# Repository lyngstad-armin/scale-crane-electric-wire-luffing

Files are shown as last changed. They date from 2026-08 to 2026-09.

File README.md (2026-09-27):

# Bachelor Project:<br>Electric AHC Knuckle Boom

## Contents
- [User Manual](./User%20Manual/)
  - [Usage](./User%20Manual/usage.md)
  - [Rigging Guide](./User%20Manual/rigging-guide.md)
  - [Limitations](./User%20Manual/limitations.md)
- [CAD Files](./CAD/CAD_catalogue.md)
- [Assembly Guide & BOM](./Assembly%20Guide/ASSEMBLY.md)
- [Wiring Schematics](./Wiring%20Schematics/)

  - [System](./Wiring%20Schematics/SYSTEM_wiring.md)
  - [MRU & Server](./Wiring%20Schematics/MRU_wiring.md)
  - [Remote Control](./Wiring%20Schematics/RC_wiring.md)
  - [Crane Control Module](./Wiring%20Schematics/CCM_wiring.md)
  
  - [Stewart Platform](./Wiring%20Schematics/PLATFORM_wiring.md)
- [Firmware Documentation](./Firmware%20Documentation/)

  - [Crane Control Module](./Firmware%20Documentation/Crane%20Control%20Module/)     [[main.py]](/Firmware%20Documentation/Crane%20Control%20Module/main.py)
  - [Remote Control](./Firmware%20Documentation/Remote%20Control/)                   [[main.py]](/Firmware%20Documentation/Remote%20Control/main.py)

  - [Onboard Server](./Firmware%20Documentation/Onboard%20Server/)
  - [Motion Reference Unit](./Firmware%20Documentation/Motion%20Reference%20Unit/)

- Server / Digital Twin

According to agreement, the physical model of the crane & motion platform, in addition to necessary electronics and access to software, has been purchased by HVL (WNUoAS).

The associated IP, however, belongs to Palfinger Marine Norway AS, and shall be treated as such.
HVL retains no right to modify / manufacture / develop this concept further.
<br><br><br>
Designed, Built, Developed & Authored by 
<br><br>**Armin Lyngstad**, *reachable on ajlyngst@stud.ntnu.no*<br>
& <br>
**Jonas Hannisdal**,

# ***Please note that the documentation is a WIP and will be updated regularly to provide necessary information to safely operate and service the product***

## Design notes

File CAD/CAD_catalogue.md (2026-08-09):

# CAD Catalogue <br> File Explorer
[Back](../README.md)

## Contents
 - [Crane](#crane)
 - [Stewart Platform](#stewart-platform)
 - [Remote](#remote)

### **Crane**
|Part No. |Description |Amount |STL | CAD |
|-|-|-|-|-|
|**KBW-PD** | **Pedestal Assembly** |1|| N/A |
|KBW-PD-01 | Pedestal Bottom Plate | 1 | [File](./Modeling%20Format/Crane/Pedestal/KBW-PD-01.stl)| N/A |
|KBW-PD-02 | Pedestal Main Body | 1 | [File](./Modeling%20Format/Crane/Pedestal/KBW-PD-02.stl)| N/A |
|KBW-PD-03 | Slewing Motor Bracket | 1 | [File](./Modeling%20Format/Crane/Pedestal/KBW-PD-03.stl)| N/A |
|KBW-PD-04 | Gear Reduction Adapter | 2 | [File](./Modeling%20Format/Crane/Pedestal/KBW-PD-04.stl)| N/A |
|KBW-PD-05 | Slewing Gear | 2 | [File](./Modeling%20Format/Crane/Pedestal/KBW-PD-05.stl)| N/A |
---
|Part No. |Description |Amount |STL | CAD |
|-|-|-|-|-|
|**KBW-SB** | **Slewing Base Assembly** |1|| N/A |
| KBW-SB-01 | Slewing Base | 1 | [File](./Modeling%20Format/Crane/Slewing%20Base/KBW-SB-01.stl)| N/A |
| KBW-SB-02 | Outer Bearing | 2 | [File](./Modeling%20Format/Crane/Slewing%20Base/KBW-SB-02.stl)| N/A |
| KBW-SB-03 | Inner Bearing | 2 | [File](./Modeling%20Format/Crane/Slewing%20Base/KBW-SB-03.stl)| N/A |
| KBW-SB-04 | Bearing Pin | 140 | [File](./Modeling%20Format/Crane/Slewing%20Base/KBW-SB-04.stl)| N/A |
| KBW-SB-05 | Sheave Bracket | 1 | [File](./Modeling%20Format/Crane/Slewing%20Base/KBW-SB-05.stl)| N/A |
| KBW-SB-06 | Sheave Pin | 1 | [File](./Modeling%20Format/Crane/Slewing%20Base/KBW-SB-06.stl)| N/A |
---
|Part No. |Description |Amount |STL | CAD |
|-|-|-|-|-|
|**KBW-AF** | **A-Frame Assembly** |1|| N/A |
| KBW-AF-01 | A-Frame | 1 | [File](./Modeling%20Format/Crane/A-Frame/KBW-AF-01.stl)| N/A |
| KBW-AF-02 | Winch Plate | 3 | [File](./Modeling%20Format/Crane/A-Frame/KBW-AF-02.stl)| N/A |
| KBW-AF-03 | Winch Crown Gear | 3 | [File](./Modeling%20Format/Crane/A-Frame/KBW-AF-03.stl)| N/A |
| KBW-AF-04 | Winch Pinion Gear | 3 | [File](./Modeling%20Format/Crane/A-Frame/KBW-AF-04.stl)| N/A |
| KBW-AF-05 | Winch Axle | 3 | [File](./Modeling%20Format/Crane/A-Frame/KBW-AF-05.stl)| N/A |
| KBW-AF-06**A**| Winch Drum | 3 | [File](./Modeling%20Format/Crane/A-Frame/KBW-AF-06A.stl)| N/A |
| KBW-AF-06**B**| Mirrored Winch Drum | 3 | [File](./Modeling%20Format/Crane/A-Frame/KBW-AF-06B.stl)| N/A |
| KBW-AF-07 | Motor Encoder Bracket | 3 | [File](./Modeling%20Format/Crane/A-Frame/KBW-AF-07.stl)| N/A |
---
|Part No. |Description |Amount |STL | CAD |
|-|-|-|-|-|
|**KBW-BM** | **Boom Assembly** |1|| N/A |
|KBW-BM-01 | Boom | 1 | [File](./Modeling%20Format/Crane/Boom/KBW-BM-01.stl) | N/A
|KBW-BM-02 | Sheave Over Bracket | 2 |  [File](./Modeling%20Format/Crane/Boom/KBW-BM-02.stl) | N/A
|KBW-BM-03 | Sheave Under Bracket | 2 |  [File](./Modeling%20Format/Crane/Boom/KBW-BM-03.stl) | N/A
|KBW-BM-04 | Sheave Bracket Pins | 4 | [File](./Modeling%20Format/Crane/Boom/KBW-BM-04.stl) | N/A
|KBW-BM-05 | Boom Pin | 2 | [File](./Modeling%20Format/Crane/Boom/KBW-BM-05.stl) | N/A
|KBW-BM-06 | Jib Pin | 2 | [File](./Modeling%20Format/Crane/Boom/KBW-BM-06.stl) | N/A
|KBW-BM-07 | Boom Sheave | 4 | [File](./Modeling%20Format/Crane/Boom/KBW-BM-07.stl) | N/A
|KBW-BM-08 | Wire Termination Bracket | 1 | [File](./Modeling%20Format/Crane/Boom/KBW-BM-08.stl) | N/A
---
|Part No. | Description | Amount | STL | CAD |
|-|-|-|-|-|
|**KBW-JB**| **Jib Assembly** | 1 | |N/A|
|KBW-JB-01 | Jib | 1 | [File](./Modeling%20Format/Crane/Jib/KBW-JB-01.stl) | N/A
|KBW-JB-02 | Redirector Bracket | 1 |[File](./Modeling%20Format/Crane/Jib/KBW-JB-02.stl) | N/A
|KBW-JB-03 | Hoist Sheave | 1 | [File](./Modeling%20Format/Crane/Jib/KBW-JB-03.stl) | N/A
|KBW-JB-04 | Support Sheave | 2 | [File](./Modeling%20Format/Crane/Jib/KBW-JB-04.stl) | N/A
|KBW-JB-05 | Regular Sheave | 7 | [File](./Modeling%20Format/Crane/Jib/KBW-JB-05.stl) | N/A
|KBW-JB-06 | Short Shim | 4 | [File](./Modeling%20Format/Crane/Jib/KBW-JB-06.stl) | N/A
|KBW-JB-07 | Long Shim | 1 | [File](./Modeling%20Format/Crane/Jib/KBW-JB-07.stl) | N/A
|KBW-JB-09 | Redirector Pin | 1 | [File](./Modeling%20Format/Crane/Jib/KBW-JB-09.stl) | N/A
|KBW-JB-10 | Rope Exit Pin | 2 | [File](./Modeling%20Format/Crane/Jib/KBW-JB-10.stl) | N/A
|KBW-JB-11 | Rear Jib Pin | 2 | [File](./Modeling%20Format/Crane/Jib/KBW-JB-11.stl) | N/A
---
|Part No. | Description | Amount | STL | CAD |
|-|-|-|-|-|
|**KBW-CO**| **Compensator Assembly** |
|Yet to be added | 
---
### **Stewart Platform**
*Please note that the specified **amount** within each assembly is for **one** assembly,<br> whereas the specified **amount** for the assembly level **line 1** is for the entire project*
|Part No. |Description |Amount |STL | CAD |
|-|-|-|-|-|
|**SP-UV** | **Universal Joint Assembly** | **12** || N/A |
| SP-UV-01 | Knuckle | 2 | [File](./Modeling%20Format/Stewart%20Platform/Universal%20Joint/SP-UV-01.stl)| N/A |
| SP-UV-02 | Cross | 1 | [File](./Modeling%20Format/Stewart%20Platform/Universal%20Joint/SP-UV-02.stl)| N/A |
| SP-UV-03 | Cap | 4 | [File](./Modeling%20Format/Stewart%20Platform/Universal%20Joint/SP-UV-03.stl)| N/A |
---
|Part No. |Description |Amount |STL | CAD |
|-|-|-|-|-|
|**SP-GR** | **Gear Reduction Assembly** | **6** || N/A |
| SP-GR-01 | Housing | 1 | [File](./Modeling%20Format/Stewart%20Platform/Gear%20Reduction/SP-GR-01.stl)| N/A |
| SP-GR-02 | Stage 1 Lower | 1 | [File](./Modeling%20Format/Stewart%20Platform/Gear%20Reduction/SP-GR-02.stl)| N/A |
| SP-GR-03 | Stage 1 Sun Gear | 1 | [File](./Modeling%20Format/Stewart%20Platform/Gear%20Reduction/SP-GR-03.stl)| N/A |
| SP-GR-04 | Planet Gear | 6 | [File](./Modeling%20Format/Stewart%20Platform/Gear%20Reduction/SP-GR-04.stl)| N/A |
| SP-GR-05 | Stage 1 Upper | 1 | [File](./Modeling%20Format/Stewart%20Platform/Gear%20Reduction/SP-GR-05.stl)| N/A |
| SP-GR-06 | Stage 2 Lower | 1 | [File](./Modeling%20Format/Stewart%20Platform/Gear%20Reduction/SP-GR-06.stl)| N/A |
| SP-GR-07 | Stage 2 Upper | 1 | [File](./Modeling%20Format/Stewart%20Platform/Gear%20Reduction/SP-GR-07.stl)| N/A |
| SP-GR-08 | Stage 2 Sun Gear | 1 | [File](./Modeling%20Format/Stewart%20Platform/Gear%20Reduction/SP-GR-08.stl)| N/A |
---
|Part No. |Description |Amount |STL | CAD |
|-|-|-|-|-|
|**SP-TR** | **Transmission Assembly** | **6** || N/A |
| SP-TR-01 | Base Plate | 1 | [File](./Modeling%20Format/Stewart%20Platform/Transmission/SP-TR-01.stl)| N/A |
| SP-TR-02 | Top Plate | 1 | [File](./Modeling%20Format/Stewart%20Platform/Transmission/SP-TR-02.stl)| N/A |
| SP-TR-03 | Reduction Output Gear | 1 | [File](./Modeling%20Format/Stewart%20Platform/Transmission/SP-TR-03.stl)| N/A |
| SP-TR-04 | Actuator Input Gear | 1 | [File](./Modeling%20Format/Stewart%20Platform/Transmission/SP-TR-04.stl)| N/A |
| SP-TR-05 | Idler Gear | 1 | [File](./Modeling%20Format/Stewart%20Platform/Transmission/SP-TR-05.stl)| N/A |
---
|Part No. |Description |Amount |STL | CAD |
|-|-|-|-|-|
|**SP-AC** | **Actuator Assembly** | **6** || N/A |
| SP-AC-01 | Lower Connector Plate | 1 | [File](./Modeling%20Format/Stewart%20Platform/Actuator/SP-AC-01.stl)| N/A |
| SP-AC-02 | Lead Screw | 1 | [File](./Modeling%20Format/Stewart%20Platform/Actuator/SP-AC-02.stl)| N/A |
| SP-AC-04 | Housing | 1 | [File](./Modeling%20Format/Stewart%20Platform/Actuator/SP-AC-04.stl)| N/A |
| SP-AC-05 | Motion Tube | 1 | [File](./Modeling%20Format/Stewart%20Platform/Actuator/SP-AC-05.stl)| N/A |
| SP-AC-06 | Upper Connector Plate | 1 | [File](./Modeling%20Format/Stewart%20Platform/Actuator/SP-AC-06.stl)| N/A |
---
|Part No. |Description |Amount |STL | CAD |
|-|-|-|-|-|
|**SP-EE** | **End Effector Joint Assembly** | **6** || N/A |
| SP-EE-01 | Rotator | 1 | [File](./Modeling%20Format/Stewart%20Platform/End%20Effector%20Joint/SP-EE-01.stl)| N/A |
| SP-EE-02 | Housing | 1 | [File](./Modeling%20Format/Stewart%20Platform/End%20Effector%20Joint/SP-EE-02.stl)| N/A |
---
### **Remote**
|Part No. | Description | Amount | STL | CAD | 
|-|-|-|-|-|
| RMT-01 | Faceplate | 1 | [File](./Modeling%20Format/Remote/RMT-01.stl)| N/A |
| RMT-02 | Body | 1 | [File](./Modeling%20Format/Remote/RMT-02.stl)| N/A |
| RMT-03 | Backplate | 1 | [File](./Modeling%20Format/Remote/RMT-03.stl)| N/A |
| RMT-04 | Handle | 2 | [File](./Modeling%20Format/Remote/RMT-04.stl)| N/A |
| RMT-05 | Mirrored Handle | 2 | [File](./Modeling%20Format/Remote/RMT-05.stl)| N/A |
| RMT-06 | Handle Axle | 2 | [File](./Modeling%20Format/Remote/RMT-06.stl)| N/A |
| RMT-07 | Axle Collar | 2 | [File](./Modeling%20Format/Remote/RMT-07.stl) | N/A |

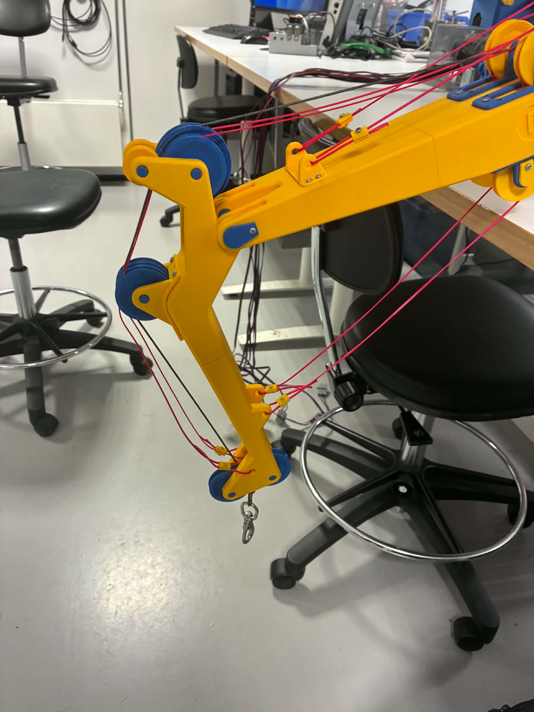
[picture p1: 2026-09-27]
.ignore/img/CRANE_TIP.jpg

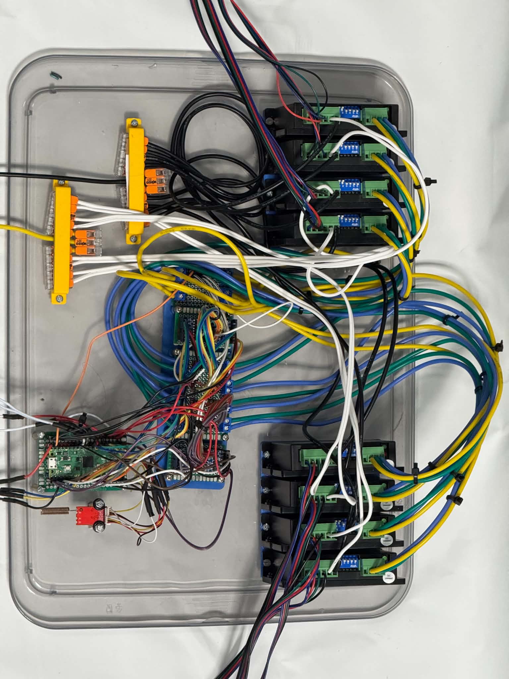
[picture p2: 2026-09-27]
.ignore/img/CCM_TOP2.jpg

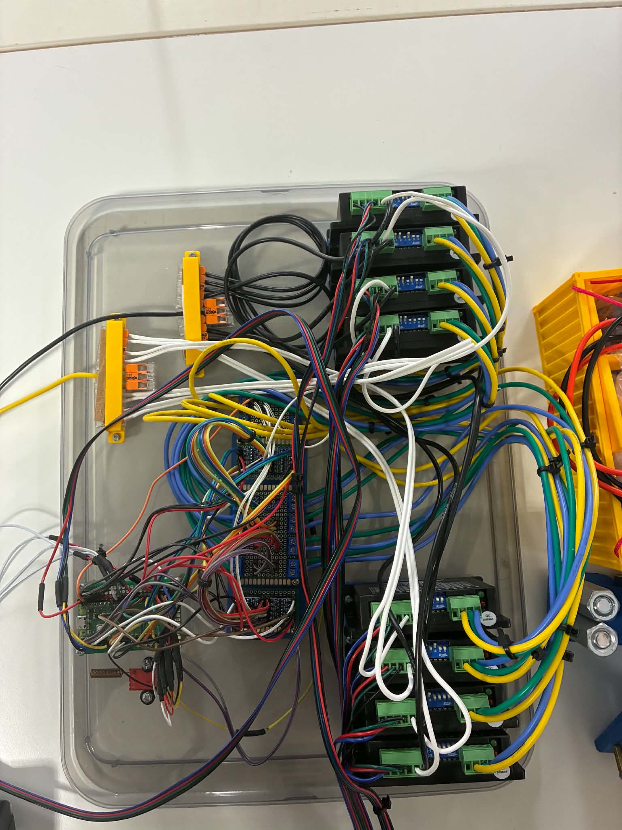
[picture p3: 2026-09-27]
.ignore/img/CCM_TOP.jpg

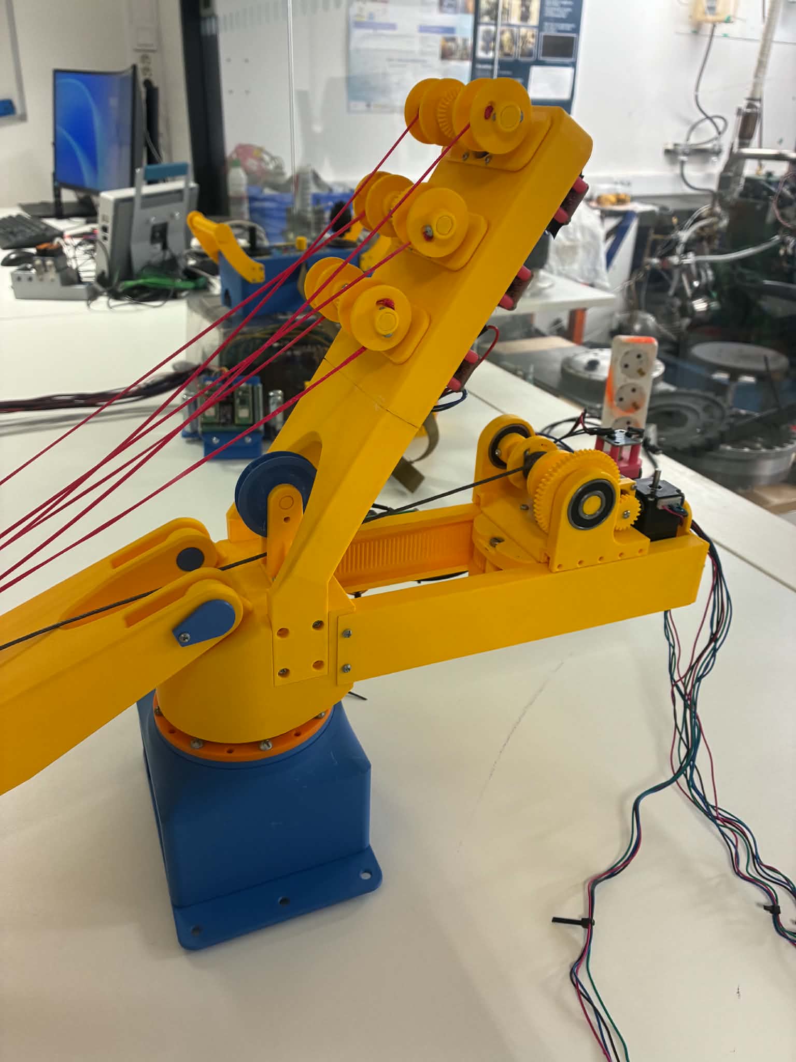
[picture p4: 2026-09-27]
.ignore/img/CRANE_REAR.jpg

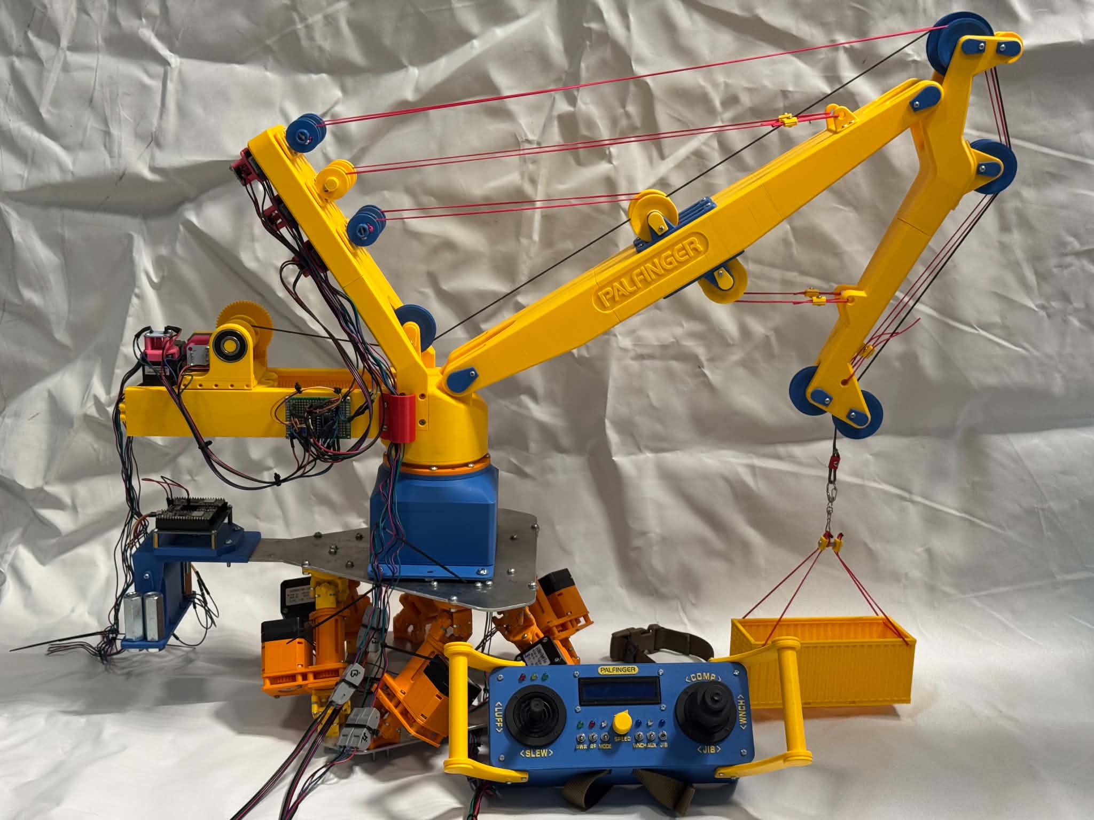
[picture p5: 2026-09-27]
.ignore/img/FULL_2.jpg

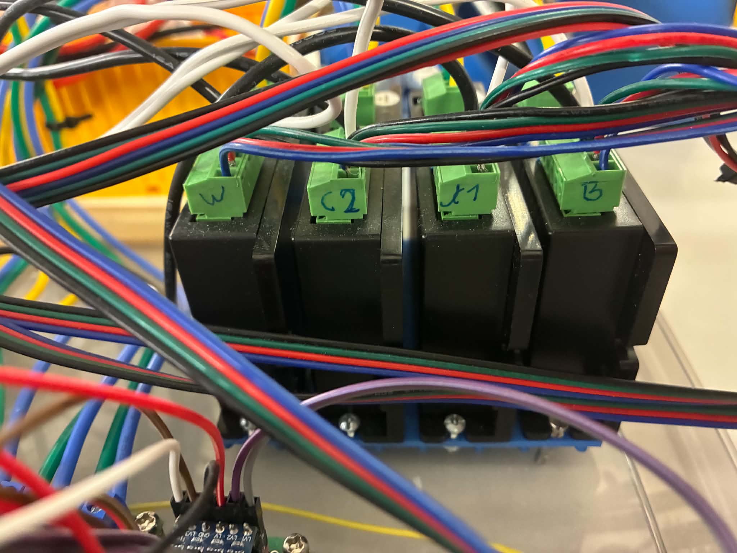
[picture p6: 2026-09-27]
.ignore/img/CCM_MARKING2.jpg

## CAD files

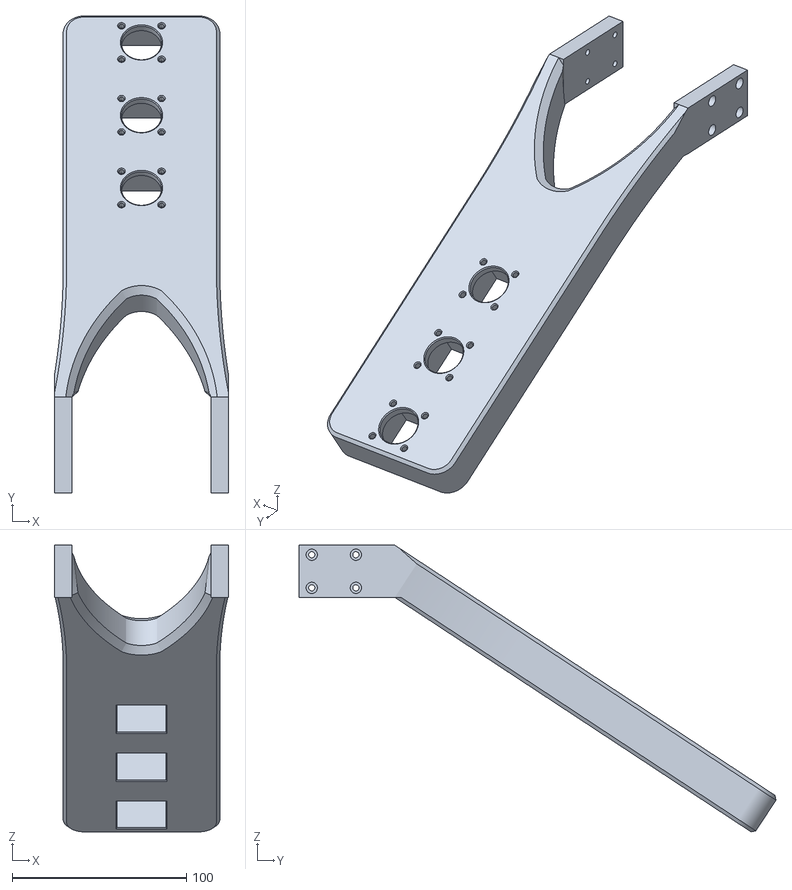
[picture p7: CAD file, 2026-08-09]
CAD/Modeling Format/Crane/A-Frame/KBW-AF-01.stl
100.0 x 273.9 x 164.6

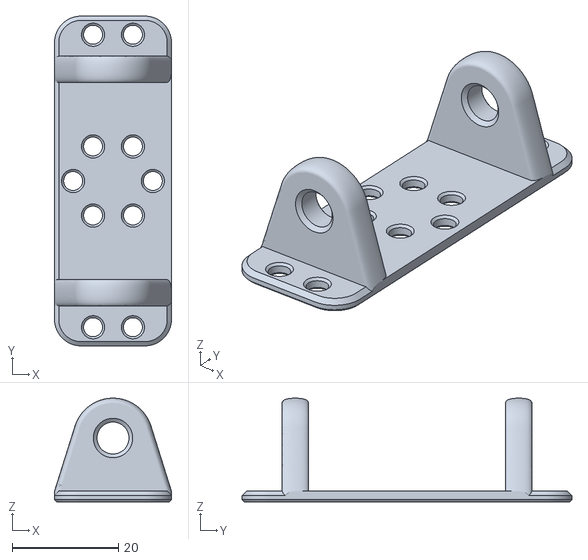
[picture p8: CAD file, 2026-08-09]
CAD/Modeling Format/Crane/Boom/KBW-BM-08.stl
22.0 x 62.0 x 19.5

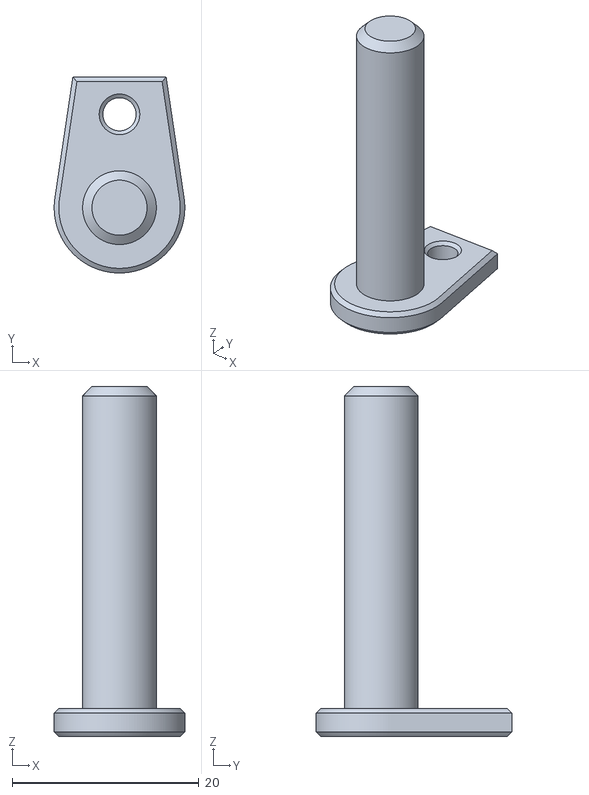
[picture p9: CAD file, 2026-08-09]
CAD/Modeling Format/Crane/Jib/KBW-JB-10.stl
14.0 x 21.0 x 37.5

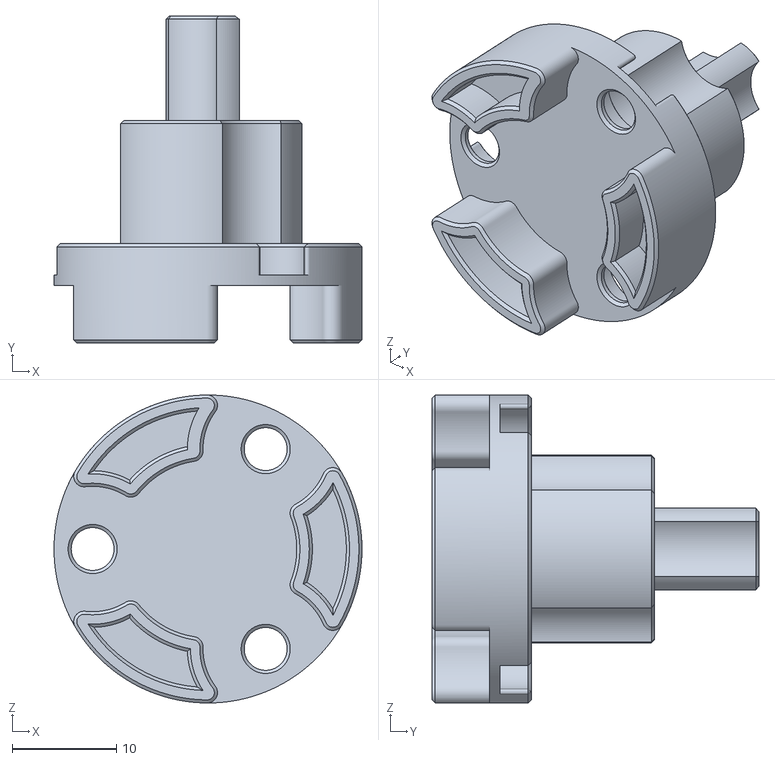
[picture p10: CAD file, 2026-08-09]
CAD/Modeling Format/Crane/Pedestal/KBW-PD-04.stl
29.5 x 31.3 x 29.5

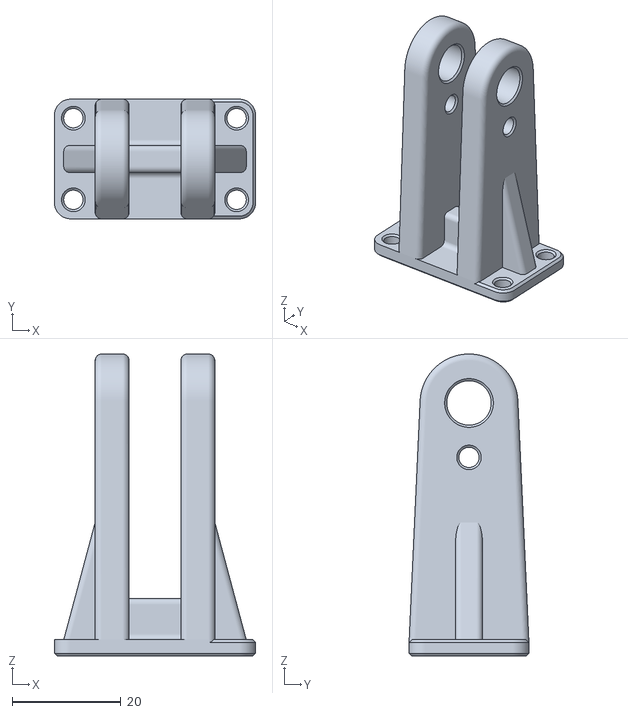
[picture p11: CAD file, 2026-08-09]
CAD/Modeling Format/Crane/Slewing Base/KBW-SB-05.stl
37.0 x 22.0 x 55.5

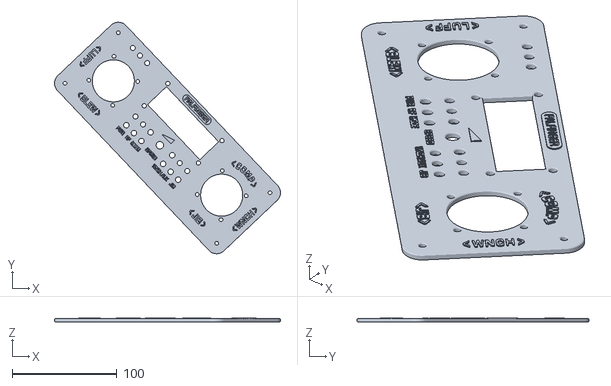
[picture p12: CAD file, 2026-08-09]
CAD/Modeling Format/Remote/RMT-01.stl
215.3 x 220.6 x 3.60

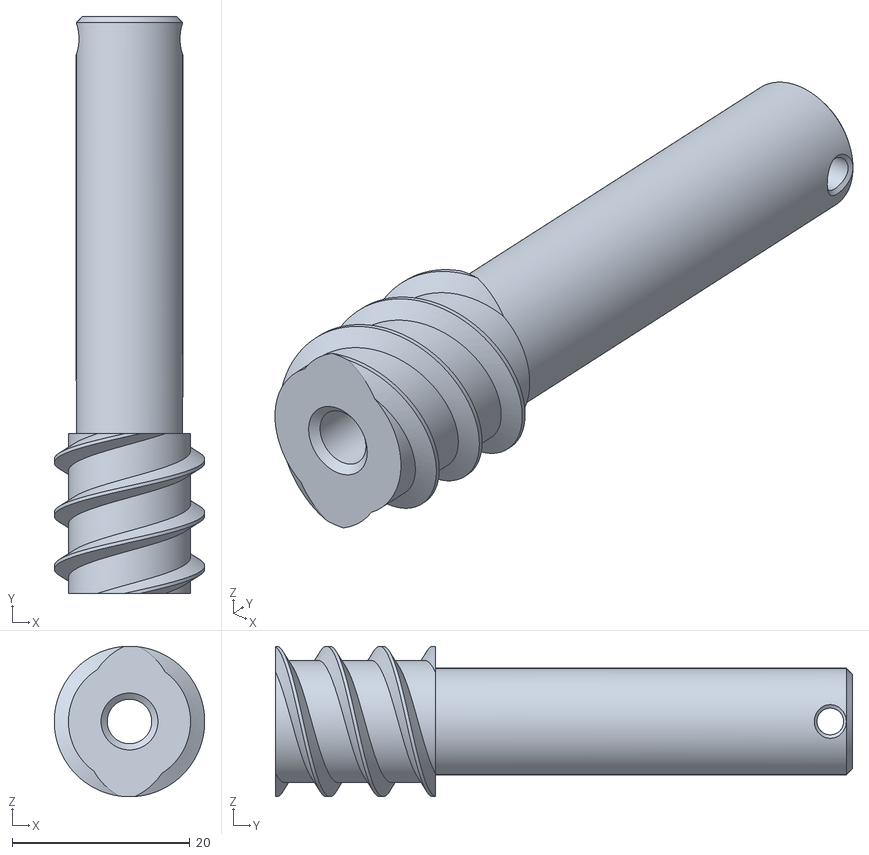
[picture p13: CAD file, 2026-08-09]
CAD/Modeling Format/Stewart Platform/Actuator/SP-AC-02.stl
16.9 x 65.0 x 16.9

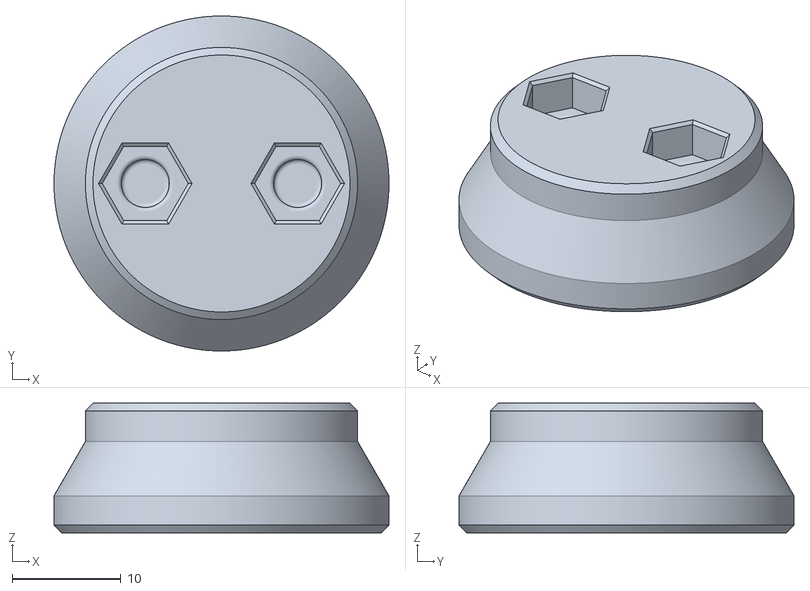
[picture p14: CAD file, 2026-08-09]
CAD/Modeling Format/Stewart Platform/End Effector Joint/SP-EE-01.stl
30.8 x 30.8 x 11.9

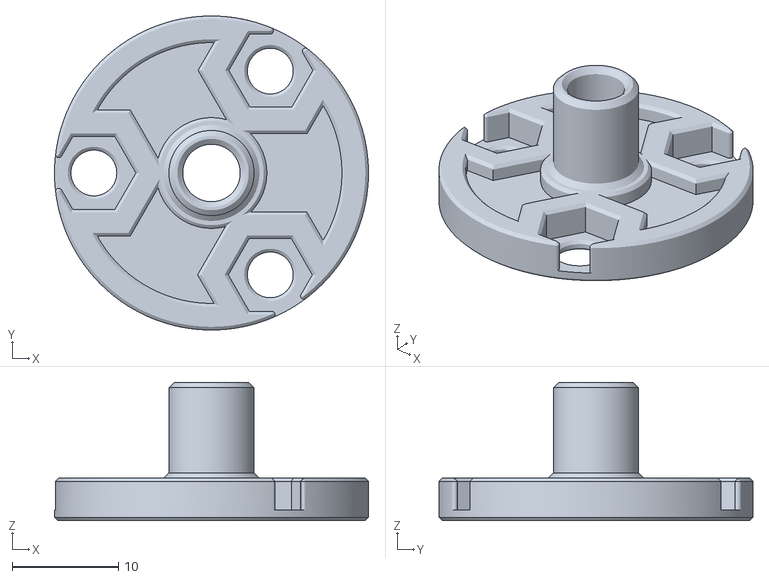
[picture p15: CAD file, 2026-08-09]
CAD/Modeling Format/Stewart Platform/Gear Reduction/SP-GR-05.stl
29.5 x 29.5 x 13.0

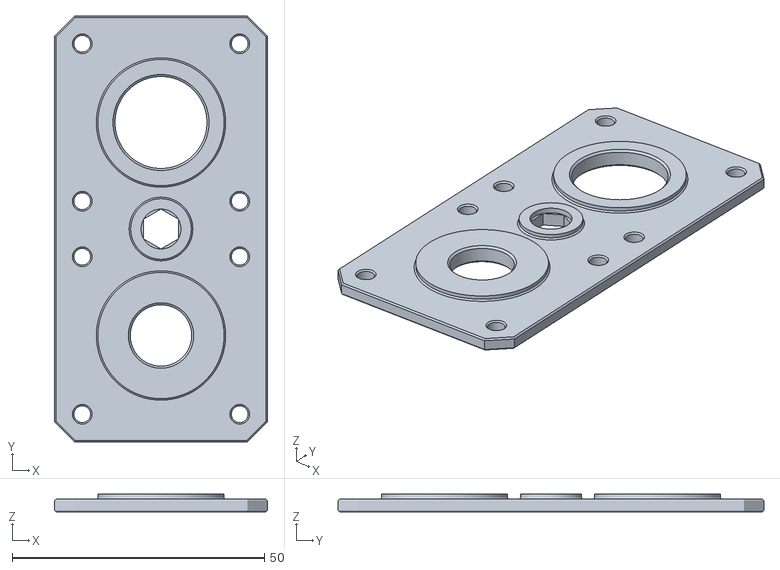
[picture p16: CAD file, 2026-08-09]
CAD/Modeling Format/Stewart Platform/Transmission/SP-TR-02.stl
42.2 x 84.4 x 3.50

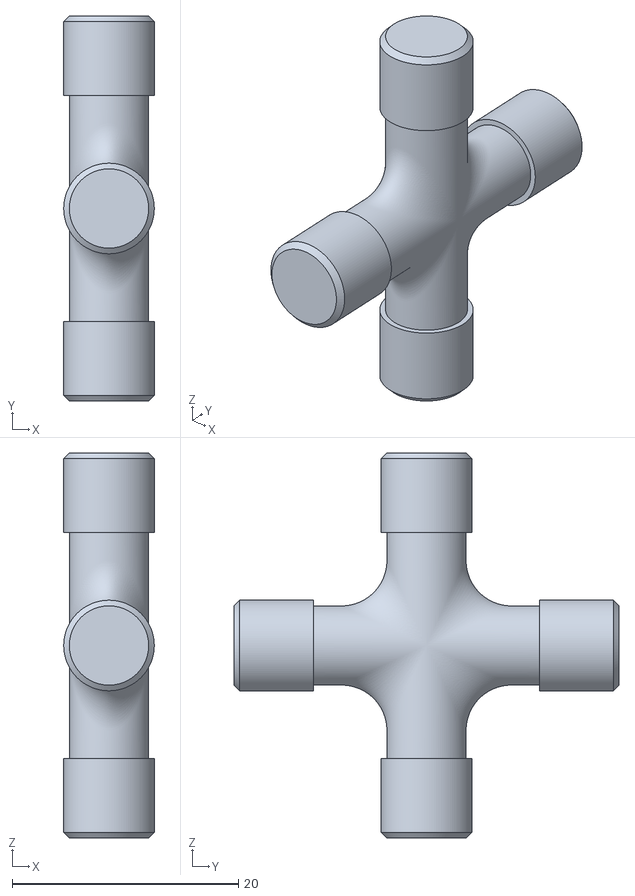
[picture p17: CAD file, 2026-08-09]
CAD/Modeling Format/Stewart Platform/Universal Joint/SP-UV-02.stl
8.00 x 34.0 x 34.0

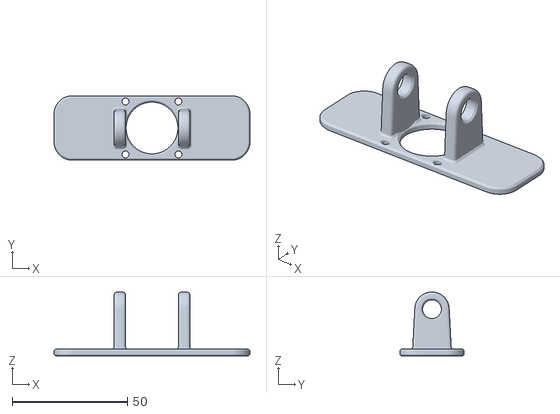
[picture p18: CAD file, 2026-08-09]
CAD/Modeling Format/Crane/A-Frame/KBW-AF-02.stl
85.2 x 28.0 x 27.8

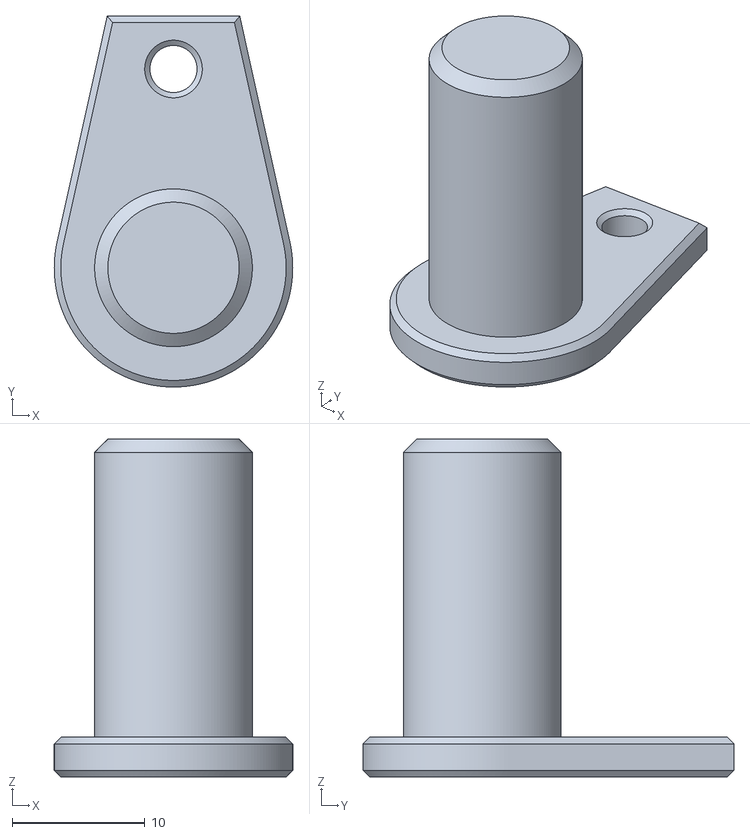
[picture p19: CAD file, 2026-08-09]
CAD/Modeling Format/Crane/Boom/KBW-BM-06.stl
18.0 x 28.0 x 25.5

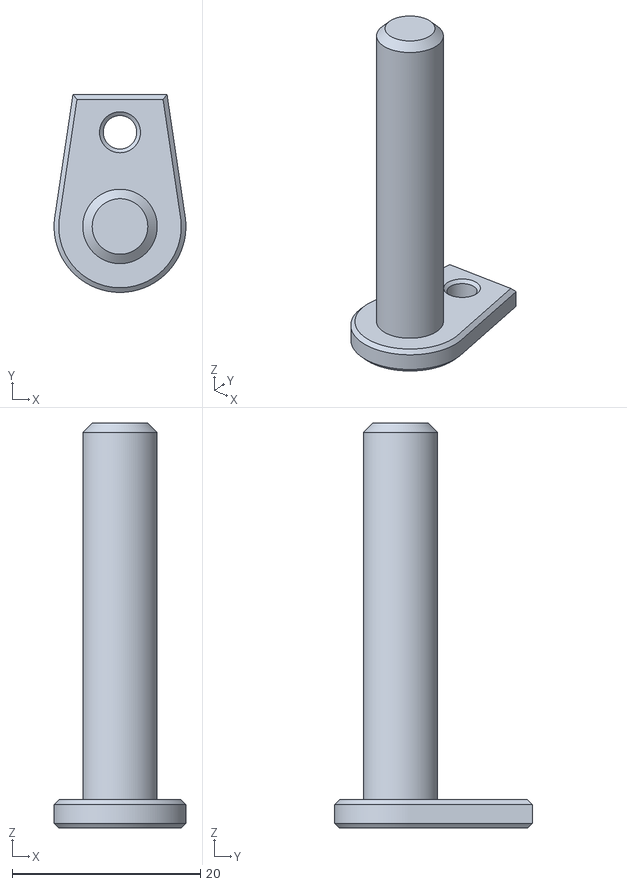
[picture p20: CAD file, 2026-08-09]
CAD/Modeling Format/Crane/Jib/KBW-JB-09.stl
14.0 x 21.0 x 43.0

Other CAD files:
CAD/Modeling Format/Crane/Pedestal/KBW-PD-03.stl
CAD/Modeling Format/Crane/Slewing Base/KBW-SB-02.stl
CAD/Modeling Format/Remote/RMT-05.stl
CAD/Modeling Format/Stewart Platform/Actuator/SP-AC-01.stl
CAD/Modeling Format/Crane/A-Frame/KBW-AF-03.stl
CAD/Modeling Format/Crane/A-Frame/KBW-AF-04.stl
CAD/Modeling Format/Crane/A-Frame/KBW-AF-05.stl
CAD/Modeling Format/Crane/A-Frame/KBW-AF-06A.stl
CAD/Modeling Format/Crane/A-Frame/KBW-AF-06B.stl
CAD/Modeling Format/Crane/A-Frame/KBW-AF-07.stl
CAD/Modeling Format/Crane/Boom/KBW-BM-02.stl
CAD/Modeling Format/Crane/Boom/KBW-BM-03.stl
CAD/Modeling Format/Crane/Boom/KBW-BM-04.stl
CAD/Modeling Format/Crane/Boom/KBW-BM-05.stl
CAD/Modeling Format/Crane/Boom/KBW-BM-07.stl
CAD/Modeling Format/Crane/Jib/KBW-JB-02.stl
CAD/Modeling Format/Crane/Jib/KBW-JB-03.stl
CAD/Modeling Format/Crane/Jib/KBW-JB-04.stl
CAD/Modeling Format/Crane/Jib/KBW-JB-05.stl
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

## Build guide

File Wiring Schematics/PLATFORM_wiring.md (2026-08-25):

# Stewart Platform <br>Wiring Schematics
[Back](../README.md)

## Commisioning/Decommisioning
```mermaid
%%{init: { 'flowchart': { 'nodeSpacing': 30, 'rankSpacing': 100, 'curve': 'linear' } } }%%
flowchart LR
classDef navy fill:#2e3c50,stroke:#5b9bd5,color:#fff
classDef crimson fill:#5c2525,stroke:#5b9bd5,color:#fff
classDef forest fill:#1f3d2b,stroke:#5b9bd5,color:#fff
classDef plum fill:#3b2e50,stroke:#5b9bd5,color:#fff
classDef teal fill:#1f3d3d,stroke:#5b9bd5,color:#fff
classDef amber fill:#5a3a1a,stroke:#5b9bd5,color:#fff
classDef magenta fill:#4a1f3d,stroke:#5b9bd5,color:#fff
classDef olive fill:#4a4a1f,stroke:#5b9bd5,color:#fff
classDef slate fill:#33383f,stroke:#5b9bd5,color:#fff
classDef indigo fill:#2a2a5c,stroke:#5b9bd5,color:#fff
classDef maroon fill:#4a1f2e,stroke:#5b9bd5,color:#fff
classDef umber fill:#3d2b1f,stroke:#5b9bd5,color:#fff
classDef steel fill:#1f3a4a,stroke:#5b9bd5,color:#fff
classDef mustard fill:#4a3f1f,stroke:#5b9bd5,color:#fff

RBPI[<br><br><br><br><br>Raspberry Pi Pico W<br><br><br><br><br><br>]
L1[Leg 1]
L2[Leg 2]
L3[Leg 3]
L4[Leg 4]
L5[Leg 5]
L6[Leg 6]

subgraph DR1[" "]
direction LR
D1
A1
end

subgraph DR2[" "]
direction LR
D2
A2
end

subgraph DR3[" "]
direction LR
D3
A3
end

subgraph DR4[" "]
direction LR
D4
A4
end

subgraph DR5[" "]
direction LR
D5
A5
end

subgraph DR6[" "]
direction LR
D6
A6
end

D1[Driver 1<br>BOB]
D2[Driver 2<br>BOB]
D3[Driver 3<br>BOB]
D4[Driver 4<br>BOB]
D5[Driver 5<br>BOB]
D6[Driver 6<br>BOB]
A1["A4988 1"]
A2["A4988 2"]
A3["A4988 3"]
A4["A4988 4"]
A5["A4988 5"]
A6["A4988 6"]

subgraph BRD[" "]
RBPI
W1[12V]
W2[GND]
USB
end

USB---|USB Micro-B|USB0["USB"]
W2---|WAGO|GND[PSU GND]
W1---|WAGO|12V[PSU 12V]

%%linkStyle 0,1,2,3,4,5 display:none

L1 ---|Connector<br>Marked 1| DR1 --- RBPI --- DR4 ---|Connector<br>Marked 4| L4
L2 ---|Connector<br>Marked 2| DR2 --- RBPI --- DR5 ---|Connector<br>Marked 5| L5
L3 ---|Connector<br>Marked 3| DR3 --- RBPI --- DR6 ---|Connector<br>Unmarked| L6

%%DR1 ---- RBPI
%%DR2 ---- RBPI
%%DR3 ---- RBPI
%%RBPI --- DR4
%%RBPI --- DR5
%%RBPI --- DR6

%%Style
RBPI:::forest
DR1:::crimson
DR2:::crimson
DR3:::crimson
DR4:::crimson
DR5:::crimson
DR6:::crimson
D1:::teal
A1:::indigo
D2:::teal
A2:::indigo
D3:::teal
A3:::indigo
D4:::teal
A4:::indigo
D5:::teal
A5:::indigo
D6:::teal
A6:::indigo
L1:::amber
L2:::amber
L3:::amber
L4:::amber
L5:::amber
L6:::amber
W1:::crimson
W2:::slate
USB:::indigo
USB0:::mustard
GND:::slate
12V:::crimson
```
<br>
<br>
<br>

## Platform GPIO Wiring
```mermaid
%%{init: { 'flowchart': { 'nodeSpacing': 30, 'rankSpacing': 100, 'curve': 'linear' } } }%%
flowchart LR
classDef navy fill:#2e3c50,stroke:#5b9bd5,color:#fff
classDef crimson fill:#5c2525,stroke:#5b9bd5,color:#fff
classDef forest fill:#1f3d2b,stroke:#5b9bd5,color:#fff
classDef plum fill:#3b2e50,stroke:#5b9bd5,color:#fff
classDef teal fill:#1f3d3d,stroke:#5b9bd5,color:#fff
classDef amber fill:#5a3a1a,stroke:#5b9bd5,color:#fff
classDef magenta fill:#4a1f3d,stroke:#5b9bd5,color:#fff
classDef olive fill:#4a4a1f,stroke:#5b9bd5,color:#fff
classDef slate fill:#33383f,stroke:#5b9bd5,color:#fff
classDef indigo fill:#2a2a5c,stroke:#5b9bd5,color:#fff
classDef maroon fill:#4a1f2e,stroke:#5b9bd5,color:#fff
classDef umber fill:#3d2b1f,stroke:#5b9bd5,color:#fff
classDef steel fill:#1f3a4a,stroke:#5b9bd5,color:#fff
classDef mustard fill:#4a3f1f,stroke:#5b9bd5,color:#fff

D1[Driver 1<br> BOB]
D2[Driver 2<br> BOB]
D3[Driver 3<br> BOB]
D4[Driver 4<br> BOB]
D5[Driver 5<br> BOB]
D6[Driver 6<br> BOB]

subgraph RBPI[Raspberry Pi Pico W]
    GPX1
    GPX2
    GPX3
    GPX4
    GPX5
    GPX6
    GPX7
    GPX8
    GPX9
    GPX10
    GPX11
    GPX12
end

GPX1 --- GPX7
GPX2 --- GPX8
GPX3 --- GPX9
GPX4 --- GPX10
GPX5 --- GPX11
GPX6 --- GPX12
linkStyle 0,1,2,3,4,5 display:none

D1 ---|PUL| GPX1
D1 ---|DIR| GPX2

D2 ---|PUL| GPX3
D2 ---|DIR| GPX4

D3 ---|PUL| GPX5
D3 ---|DIR| GPX6

GPX7 ---|PUL| D4
GPX8 ---|DIR| D4

GPX9 ---|PUL| D5
GPX10 ---|DIR| D5

GPX11 ---|PUL| D6
GPX12 ---|DIR| D6

%%Style
D1:::teal
D2:::teal
D3:::teal
D4:::teal
D5:::teal
D6:::teal
RBPI:::forest
GPX1:::plum
GPX2:::maroon
GPX3:::plum
GPX4:::maroon
GPX5:::plum
GPX6:::maroon
GPX7:::plum
GPX8:::maroon
GPX9:::plum
GPX10:::maroon
GPX11:::plum
GPX12:::maroon

%%Name
GPX1["GP0"]
GPX2["GP1"]
GPX3["GP8"]
GPX4["GP9"]
GPX5["GP6"]
GPX6["GP5"]
GPX7["GP28"]
GPX8["GP18"]
GPX9["GP26"]
GPX10["GP22"]
GPX11["GP21"]
GPX12["GP19"]
```
<br>
<br>
<br>

## Platform Power Wiring
```mermaid
%%{init: { 'flowchart': { 'nodeSpacing': 30, 'rankSpacing': 100, 'curve': 'linear' } } }%%
flowchart TB
classDef navy fill:#2e3c50,stroke:#5b9bd5,color:#fff
classDef crimson fill:#5c2525,stroke:#5b9bd5,color:#fff
classDef forest fill:#1f3d2b,stroke:#5b9bd5,color:#fff
classDef plum fill:#3b2e50,stroke:#5b9bd5,color:#fff
classDef teal fill:#1f3d3d,stroke:#5b9bd5,color:#fff
classDef amber fill:#5a3a1a,stroke:#5b9bd5,color:#fff
classDef magenta fill:#4a1f3d,stroke:#5b9bd5,color:#fff
classDef olive fill:#4a4a1f,stroke:#5b9bd5,color:#fff
classDef slate fill:#33383f,stroke:#5b9bd5,color:#fff
classDef indigo fill:#2a2a5c,stroke:#5b9bd5,color:#fff
classDef maroon fill:#4a1f2e,stroke:#5b9bd5,color:#fff
classDef umber fill:#3d2b1f,stroke:#5b9bd5,color:#fff
classDef steel fill:#1f3a4a,stroke:#5b9bd5,color:#fff
classDef mustard fill:#4a3f1f,stroke:#5b9bd5,color:#fff

D1[Driver 1<br> BOB]
D2[Driver 2<br> BOB]
D3[Driver 3<br> BOB]
D4[Driver 4<br> BOB]
D5[Driver 5<br> BOB]
D6[Driver 6<br> BOB]

subgraph PSU
    GND[Common GND]
    12V
end

subgraph DRV[" "]
    D1
    D2
    D3
    D4
    D5
    D6
end

subgraph RB["Raspberry Pi Pico W"]
    VBUS[VBUS<br>5V]
    USB
    3.3V
    GN[GND]
end

GND ---|To all BOB| D1 & D4
12V ---|To all BOB| D1 & D4
D3 & D6 ---|To all BOB| VBUS
GND --- GN

linkStyle 0,1,6 stroke:#2A2A2A,stroke-width:5px
linkStyle 2,3,4,5 stroke:#FF4D4D,stroke-width:4px
USB --- USB0["USB"]
linkStyle 7 stroke:#4a4,stroke-width:6px

D1 --- D2 --- D3
D4 --- D5 --- D6

%%style
12V:::crimson
VBUS:::crimson
GND:::slate
GN:::slate
RB:::forest
USB:::indigo
USB0:::mustard
3.3V:::crimson
PSU:::navy
DRV:::steel
D1:::teal
D2:::teal
D3:::teal
D4:::teal
D5:::teal
D6:::teal
```

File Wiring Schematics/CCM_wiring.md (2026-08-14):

# Crane Control Module<br>Wiring Diagrams
[Back](../README.md)
## External Communication / I2C Bus / Driver Wiring

```mermaid
%%{init: {'flowchart': {'curve': 'linear'}}}%%
flowchart LR
classDef style2 fill:#2e3c50,stroke:#5b9bd5,color:#fff
classDef style1 fill:#5c2525,stroke:#5b9bd5,color:#fff
classDef style3 fill:#242b2b,stroke:#5b9bd5,color:#fff
subgraph Driver Wiring
    direction TD

    DM1[Slew 1]:::style3
    DM2[Slew 2]:::style3
    DM3[Boom]:::style3
    DM4[Jib Under]:::style3
    DM5[Jib Over]:::style3
    DM6[Hoist]:::style3
    DM7[Comp 1]:::style3
    DM8[Comp 2]:::style3

    LLS1[Shifter 1]:::style1
    LLS2[Shifter 2]:::style1
    LLS3[Shifter 3]:::style1
    LLS4[Shifter 4]:::style1

    GPX1:::style2
    GPX2:::style2
    GPX3:::style2
    GPX4:::style2
    GPX5:::style2
    GPX6:::style2
    GPX7:::style2
    GPX8:::style2
    GPX01:::style2
    GPX02:::style2
    GPX03:::style2
    GPX04:::style2
    GPX05:::style2
    GPX06:::style2
    GPX07:::style2
    GPX08:::style2

%%linkStyle 0,1 display:none
GPX2 ---|PUL 3.3V| LLS1 ---|PUL 5V| DM1
GPX4 ---|PUL 3.3V| LLS1 ---|PUL 5V| DM2

GPX6 ---|PUL 3.3V| LLS2 ---|PUL 5V| DM3
GPX8 ---|PUL 3.3V| LLS2 ---|PUL 5V| DM4

GPX02 ---|PUL 3.3V| LLS3 ---|PUL 5V| DM5
GPX04 ---|PUL 3.3V| LLS3 ---|PUL 5V| DM6

GPX06 ---|PUL 3.3V| LLS4 ---|PUL 5V| DM7
GPX08 ---|PUL 3.3V| LLS4 ---|PUL 5V| DM8

GPX1 ---|DIR 3.3V| LLS1 ---|DIR 5V| DM1
GPX3 ---|DIR 3.3V| LLS1 ---|DIR 5V| DM2

GPX5 ---|DIR 3.3V| LLS2 ---|DIR 5V| DM3
GPX7 ---|DIR 3.3V| LLS2 ---|DIR 5V| DM4

GPX01 ---|DIR 3.3V| LLS3 ---|DIR 5V| DM5
GPX03 ---|DIR 3.3V| LLS3 ---|DIR 5V| DM6

GPX05 ---|DIR 3.3V| LLS4 ---|DIR 5V| DM7
GPX07 ---|DIR 3.3V| LLS4 ---|DIR 5V| DM8
end
```

```mermaid
flowchart LR
classDef style2 fill:#2e3c50,stroke:#5b9bd5,color:#fff
    classDef style1 fill:#5c2525,stroke:#5b9bd5,color:#fff
    classDef style3 fill:#242b2b,stroke:#5b9bd5,color:#fff
subgraph I2C Multiplexer Wiring
    GP1[GPX SDA]:::style2
    GP2[GPX SCL]:::style2

    MPXSD[SDA]:::style1
    MPXSC[SCL]:::style1
    SDA7:::style1
    SCL7:::style1
    SDA6:::style1
    SCL6:::style1
    SDA5:::style1
    SCL5:::style1
    SDA4:::style1
    SCL4:::style1
    SDA3:::style1
    SCL3:::style1

    ENC1[Jib Over]:::style3
    ENC2[Boom]:::style3
    ENC3[Jib Under]:::style3
    ENC4[Hoist]:::style3
    ENC5[Winch]:::style3

    X991[" "]
    style X991 display:none

GP1 --- MPXSD
GP2 --- MPXSC
SDA7 & SCL7 --- ENC1
SDA6 & SCL6 --- ENC2
SDA5 & SCL5 --- ENC3
SDA4 & SCL4 --- ENC4
SDA3 & SCL3 --- ENC5
MPXSD & MPXSC --- X991
SP1[CCM PICO]:::style2 --- SP2[MULTIPLEXER]:::style1 --- SP3[ENCODERS]:::style3
linkStyle 12,13,14,15 display:none

end
```

## Power Wiring CCM

```mermaid
%%{init: {'flowchart': {'curve': 'linear'}}}%%
flowchart TB

    classDef style2 fill:#2e3c50,stroke:#5b9bd5,color:#fff
    classDef style1 fill:#5c2525,stroke:#5b9bd5,color:#fff
    classDef style3 fill:#242b2b,stroke:#5b9bd5,color:#fff

subgraph Power Wiring
PSU:::style3
GND:::style3
12V:::style1
Driver:::style2
P5[Pico VBUS / 5V]:::style1
P3[Pico 3.3V]:::style1
LSH[Shifter]:::style2
PG[Pico GND]:::style3 

PSU ---> 12V --- Driver --- P5
GND --- LSH ---|LV| P3
linkStyle 3 display:none
GND --- Driver
PG ---|HV-side| LSH ---|HV| P5
LSH ---|LV-Side| PG

PSU ---> GND
end
```

## Absolute CCM Pico I/O Wiring

```mermaid
%%{init: {'flowchart': {'curve': 'linear'}}}%%
flowchart TB

    classDef style2 fill:#2e3c50,stroke:#5b9bd5,color:#fff
    classDef style1 fill:#5c2525,stroke:#5b9bd5,color:#fff
    classDef style3 fill:#242b2b,stroke:#5b9bd5,color:#fff

subgraph Absolute I/O

    subgraph CCM
    USB["USB"]:::style1
    GP0:::style1
    GP1:::style1
    GP2:::style1
    GP3:::style1
    GP4:::style1
    GP5:::style1
    GP6:::style1
    GP7:::style1
    GP8:::style1
    GP9:::style1
    GP10:::style1
    GP11:::style1
    GP12:::style1
    GP13:::style1
    GP14:::style1
    GP15:::style1
    GP16:::style1
    GP17:::style1
    GP18:::style1
    GP19:::style1
    GP20:::style1
    GP21:::style1
    GP22:::style1
    GP26:::style1
    GP27:::style1
    GP28:::style1
    end

    subgraph INPUT
    USBI[USB]:::style3

    TX[UART TX]:::style3
    RX[UART RX]:::style3
    MISO:::style3
    MOSI:::style3
    SCK:::style3
    CS:::style3
    SDA[SDA]:::style3
    SCL[SCL]:::style3
    end

    subgraph OUTPUT
    TXU[UART TX]:::style2
    RXU[UART TX]:::style2

    MOSIU[MOSI]:::style2
    MISOU[MISO]:::style2
    SCKU[SCK]:::style2
    CSU[CS]:::style2

    SDAU[SDA]:::style2
    SCLU[SCL]:::style2

    JO[Jib Over]:::style2
    JU[Jib Under]:::style2
    S1[Slew 1]:::style2
    S2[Slew 2]:::style2
    Hoist:::style2
    C1[Comp 1]:::style2
    C2[Comp 2]:::style2
    Boom:::style2
    end

    CCM[CCM PICO]:::style1
    INPUT[Input]:::style3
    OUTPUT[Output]:::style2

USBI --- USB
TX --- GP4 --- TXU
RX --- GP5 --- RXU
GP0 --- |PUL| JU
GP1 --- |DIR| JU
GP3 --- |PUL| JO
GP2 --- |DIR| JO
GP8 --- |PUL| C1
GP20 --- |DIR| C1
GP11 --- |PUL| C2
GP10 --- |DIR| C2
GP13 --- |PUL| Hoist
GP12 --- |DIR| Hoist
GP15 --- |PUL| Boom
GP14 --- |DIR| Boom
GP6 --- |PUL| S1
GP7 --- |DIR| S1
GP22 --- |PUL| S2
GP21 --- |DIR| S2
SDA --- GP26 --- SDAU
SCL --- GP27 --- SCLU
SCK --- GP18 --- SCKU
MISO --- GP16 --- MOSIU
MOSI --- GP19 --- MISOU
CS --- GP17 --- CSU
end
```

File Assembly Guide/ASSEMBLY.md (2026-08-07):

# Assembly <br>Guide
[Back](../README.md)

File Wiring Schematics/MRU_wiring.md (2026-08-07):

# MRU & Server <br>Wiring Schematics
[Back](../README.md)

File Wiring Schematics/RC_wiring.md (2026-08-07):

# Remote Control <br>Wiring Schematics
[Back](../README.md)

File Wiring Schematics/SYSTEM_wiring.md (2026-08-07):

# System Architechure &<br>Intermodular Wiring Schematic
[Back](../README.md)
## Intermodular Connections
```mermaid
%%{init: {'flowchart': {'curve': 'linear'}}}%%
flowchart TB
    classDef style2 fill:#2e3c50,stroke:#5b9bd5,color:#fff
    classDef style1 fill:#5c2525,stroke:#5b9bd5,color:#fff
    classDef style3 fill:#242b2b,stroke:#5b9bd5,color:#fff

subgraph Remote
end

subgraph Crane
 direction LR
    CCM
    MRU
    SERVER
end

subgraph Website
end

subgraph Platform
end

CCM <--->|UART| MRU <--->|UART| SERVER

Remote <--->|SPI| CCM
SERVER --->|Websocket| Website
Website --->|Websocket| Platform

%%style
Remote:::style3
Crane:::default
CCM:::style1
MRU:::style2
SERVER:::style2
Website:::style1
Platform:::style1
```
---
## System Power Wiring
```mermaid
%%{init: {'flowchart': {'curve': 'linear'}}}%%
flowchart TB
    classDef style2 fill:#2e3c50,stroke:#5b9bd5,color:#fff
    classDef style1 fill:#5c2525,stroke:#5b9bd5,color:#fff
    classDef style3 fill:#242b2b,stroke:#5b9bd5,color:#fff

subgraph PSU
    GND
    12V:::style1
    5V:::style1
end
PSU:::style3
CCM:::style3
MRU:::style3
SERVER:::style3

PLATFORM:::style2

GND & 12V & 5V --- CCM
5V --- PLATFORM
CCM --- MRU --- SERVER
```

## Wiring for commissioning/decom
```mermaid
%%{init: {'flowchart': {'curve': 'linear'}}}%%
flowchart TB
classDef navy fill:#2e3c50,stroke:#5b9bd5,color:#fff
classDef crimson fill:#5c2525,stroke:#5b9bd5,color:#fff
classDef forest fill:#1f3d2b,stroke:#5b9bd5,color:#fff
classDef plum fill:#3b2e50,stroke:#5b9bd5,color:#fff
classDef teal fill:#1f3d3d,stroke:#5b9bd5,color:#fff
classDef amber fill:#5a3a1a,stroke:#5b9bd5,color:#fff
classDef magenta fill:#4a1f3d,stroke:#5b9bd5,color:#fff
classDef olive fill:#4a4a1f,stroke:#5b9bd5,color:#fff
classDef slate fill:#33383f,stroke:#5b9bd5,color:#fff
classDef indigo fill:#2a2a5c,stroke:#5b9bd5,color:#fff
classDef maroon fill:#4a1f2e,stroke:#5b9bd5,color:#fff
classDef umber fill:#3d2b1f,stroke:#5b9bd5,color:#fff
classDef steel fill:#1f3a4a,stroke:#5b9bd5,color:#fff
classDef mustard fill:#4a3f1f,stroke:#5b9bd5,color:#fff

subgraph PSU
    GND
    12V:::style1
    5V:::style1
end

subgraph CCM
    V5[VBUS/VSUS<br> or USB]:::style1
    GN[GND<br>or USB]
    V12["12V (Drivers)"]:::style1
    GN12["GND (Drivers)"]
    TX[UART TX]
    RX[UART RX]
    V3[3.3V]:::style1
end

subgraph MRU[MRU & SERVER]
    TX1[UART TX]
    RX1[UART RX]
    GNM[GND]
    V31[3.3V]:::style1
end

subgraph I2C
    SDA
    SCL
end

subgraph DR["Driver<br>(for each)"]
    A+
    A-
    B+
    B-
end

subgraph MT["Motor<br>(for each)"]
    GRN
    BLK
    RED
    BLU
end

subgraph Actuation
    direction TB
    DR
    MT
end
GND ---|Jumper wire<br>DNC if USB connected| GN
GND ---|WAGO| GN12
5V ---|Jumper wire<br>DNC if USB connected| V5
CCM ---|Jumper wire| SDA & SCL
12V ---|WAGO| V12

A+ ---|WAGO| BLK
A- ---|WAGO| GRN
B+ ---|WAGO| RED
B- ---|WAGO| BLU

TX ---|Jumper wire| RX1
RX ---|Jumper wire| TX1
V3 ---|Jumper wire| V31
GN ---|Jumper wire| GNM

MRU --- Actuation
linkStyle 14 display:none

%%style
PSU:::default
5V:::crimson
12V:::crimson
V3:::crimson
V31:::crimson
RX:::mustard
TX1:::mustard
TX:::plum
RX1:::plum
V12:::crimson
V5:::crimson
RED:::maroon
B+:::maroon
A-:::forest
GRN:::forest
BLU:::navy
B-:::navy
SDA:::forest
SCL:::steel

```

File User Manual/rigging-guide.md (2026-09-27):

# Rigging Guide
[Back](../README.md)

## Setup
 1. Mount Crane to Stewart Platform using 6pcs M6 screws and nuts
 ---
 2. Connect Stewart Platform leg connectors to main board<br>

 *Graphical Representation in [Platform Wiring/Commisioning](/Wiring%20Schematics/PLATFORM_wiring.md)*
 
 ---
 3. Connect Motor Wiring from Crane to CCM<br>
 Match Colors and Names (W ,C1 ,C2 ,B ,J1 ,J2 ,S1 ,S2 )

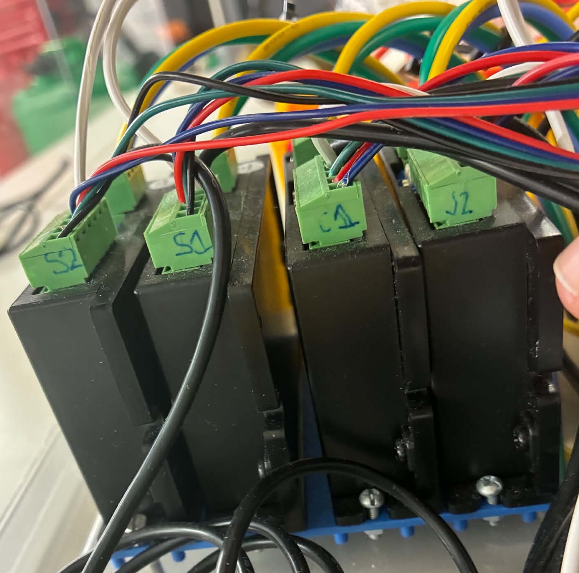
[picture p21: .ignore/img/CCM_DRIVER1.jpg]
CCM DRIVER NOTATION
 

 4. Connect I2C from Multiplexer (Rats nest on side of compensator)<br>
 Four wires; 2 jumper cables (white,grey), 2 one-sided jumpers with 16AWG ends (green)
 White,Grey are SDA/SCL lines for I2C, 16AWG wires are powersupply for multiplexer

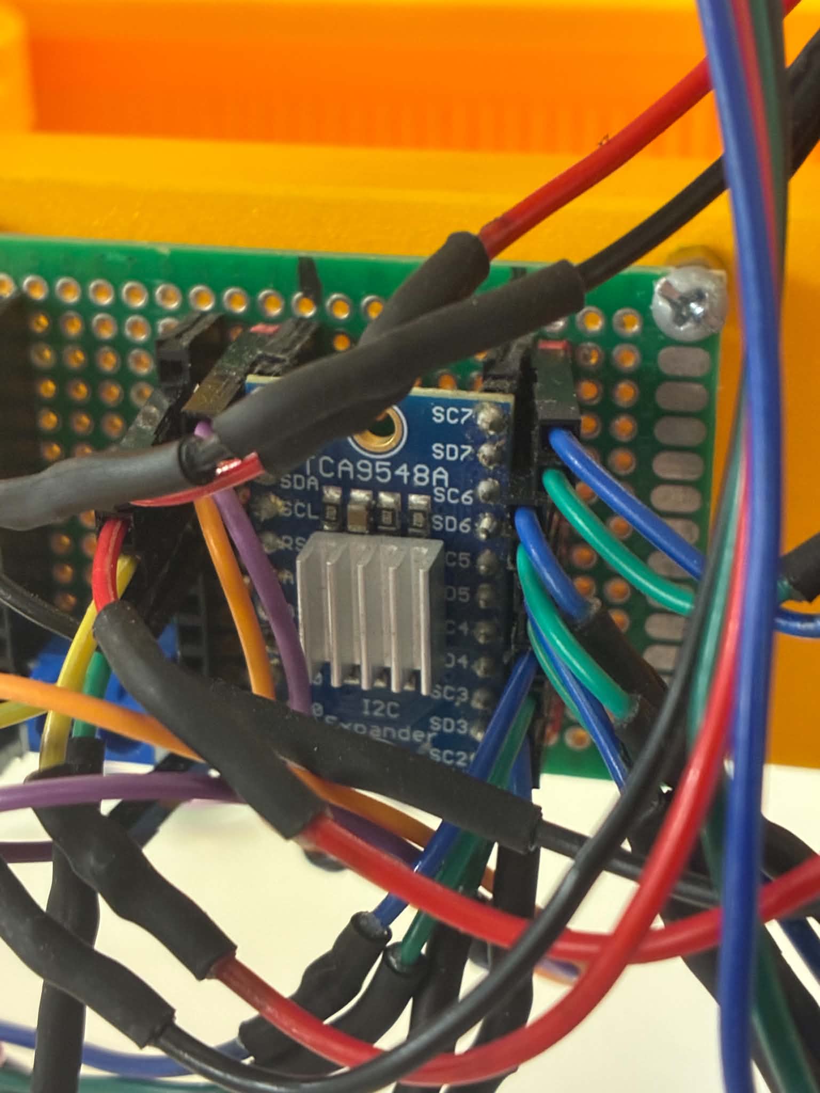
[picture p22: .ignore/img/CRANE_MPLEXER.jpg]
Multiplexer
 

 5. Connect UART Jumpers to CCM and MRU<br>
 Four wires; 4 jumper cables (blue,yellow,red,black)<br>

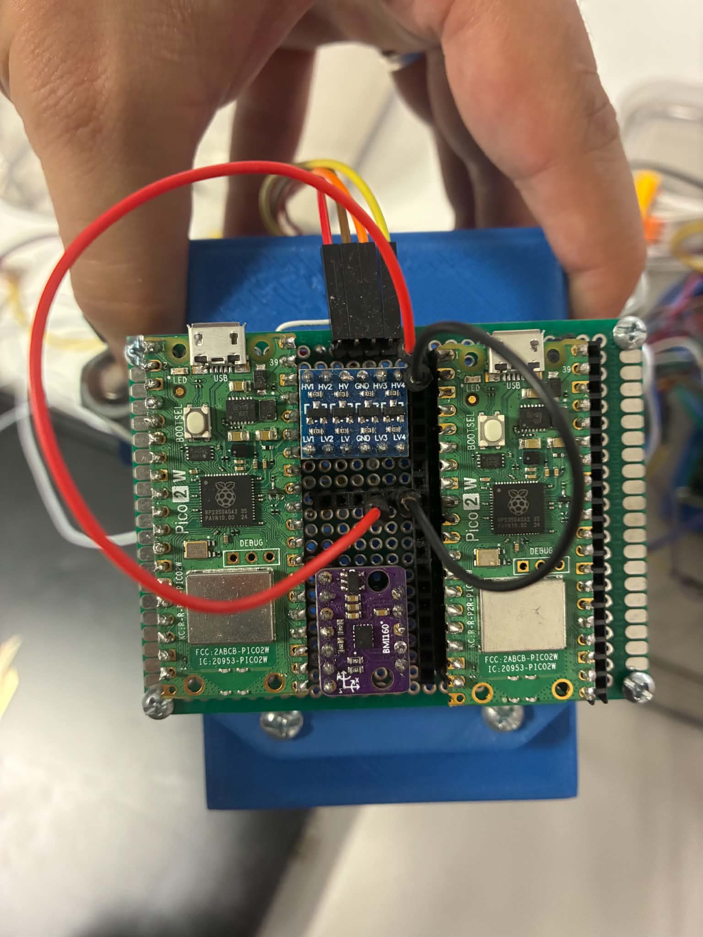
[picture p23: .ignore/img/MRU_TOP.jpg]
MRU


 *Graphical Representation in [System Wiring/Commisioning](/Wiring%20Schematics/SYSTEM_wiring.md)*
 
 ---

 6. Connect 12V Supply to both CCM and Platform Mainboard (Both boards should also be able to handle 24V, which will increase effective motor torque at speed)

 ---

 7. If controlling platform via Server, configure WiFi credentials through Thonny IDE while plugged into the Stewart Platform mainboard.
 This will also require configuring the WiFi credentials on the Server Module in the same way.

 ---

 8. Perform a simple connection check on the remote control

   - With the CCM unpowered, flick the power switch on the controller
   - Screen should read ```NLINK``` and signal indicators should blink red/green
   - Turn off remote
   - Then with the CCM **powered**, flick the power switch on the controller
   - Screen should read ```int dBm``` and signal indicators should be stable
   - If not, the remote is unable to communicate with the CCM <br>(Try flicking the antenna of the CCM and turning off and on again) <br> Should this not work, plug into the controller with Thonny IDE and read the debug REPL<br>Antenna ID should be ```0x14```
9. If the connection was successful, Crane should be ready to operate

## Wire Spooling

To ensure proper operation and response of the crane the luffing wires must spool correctly, at this scale it is especially difficult to keep the wire correctly spooled. Should the wire not have spooled correctly consider these options.
 <br>**Operating relevant winches with crane powered on**<br>
 **Unspooling/Respooling by hand with no power connected**

    - Unspool all wire on winch drum
    - With moderate tension (a respectable pinch) respool the drum
    - Push/Correct spooling as necessary underway

It is recommended to check all 7 Winches<br>
(Although the main winch does not care much for correct spooling)

*Reference Wire routing*

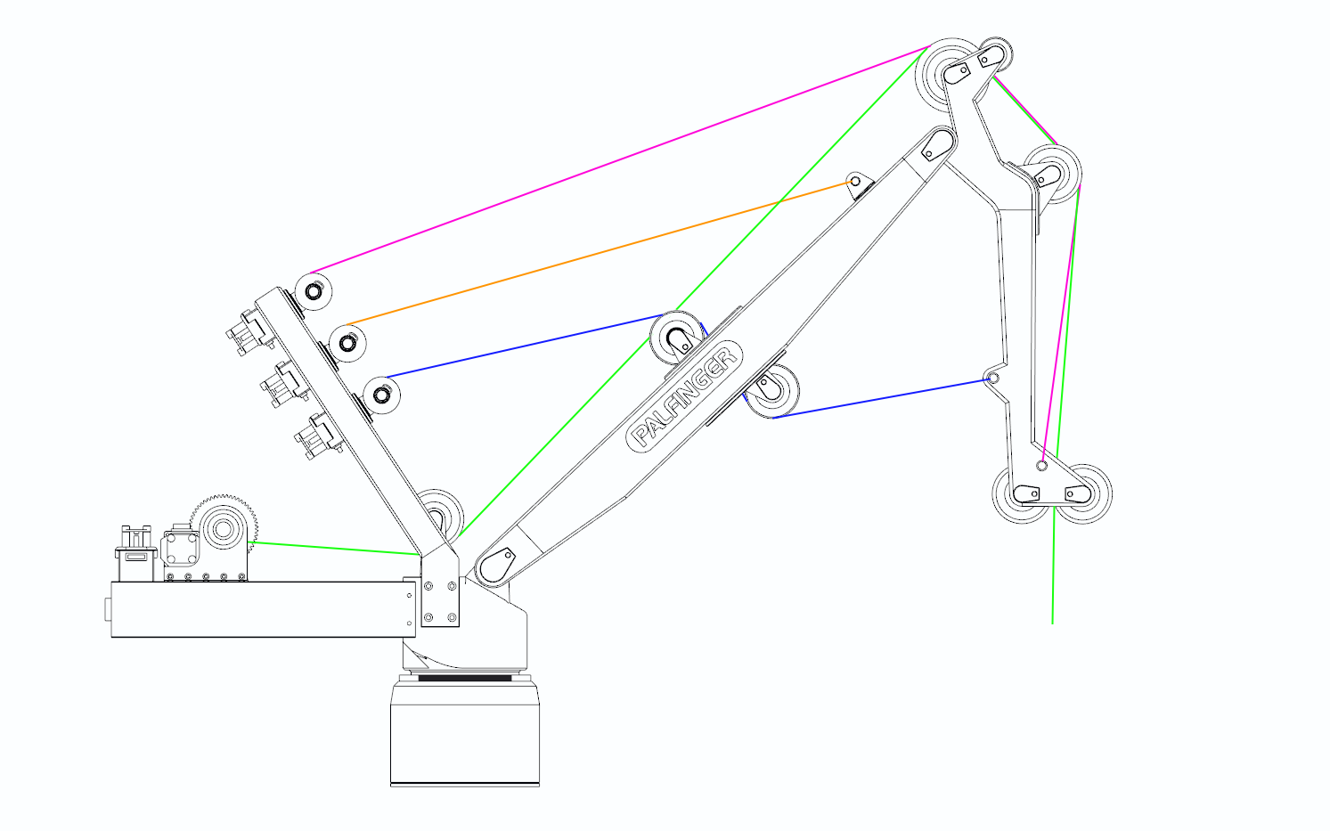
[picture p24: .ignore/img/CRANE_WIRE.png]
WIRE PATH


## Server Setup

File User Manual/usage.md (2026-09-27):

# How to Operate <br>

## Remote Control

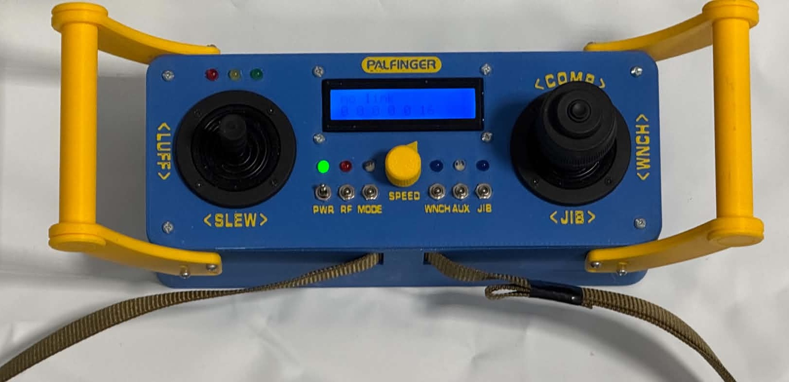
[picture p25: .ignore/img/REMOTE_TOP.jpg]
Remote


Joystick ``<SLEW>`` : Slews crane (Rotating the entire base)

Joystick ``<LUFF>`` : Operates boom (First link of crane up/down)

Joystick ``<JIB>`` : Operates jib (Second link of crane in/out)

Joystick ``<COMP>`` : Runs Compensator 'Cartridge' (Rear rail in/out)

Joystick ``<WNCH>`` : Main winch hoist (Load up/down)

Switch ``PWR`` : Power switch (Internal 9V battery)

Switch ``RF``: Encoder reset switch. Use ONLY when resetting encoders with crane in folded configuration.

Switch ``MODE``: Activate Heave Compensation.

Switch ``WNCH``: Debug Switch for reading error messages in Thonny IDE while connected to CCM

Switch ``AUX``: Unmapped

Switch ``JIB``: Switches operation mode of Jib Winches.

-``Off``: Synchronous (Both winches running)

-``On``: Only bottom wire

Knob ``Speed``:

-``button press`` : Enter menu

-``rotation`` : Adjust speed limit of each link

-``repeat button press``: Next entry in menu

## Encoder reset sequence

1. Ensure proper spooling on all winches, and run the crane to folded position.

2. Double check that all winches are tensioned at folded position.

3. Flick Switch ``RF`` On for 3 seconds, then off again.

4. Crane is now ready for operation, and Active Heave Compenstation

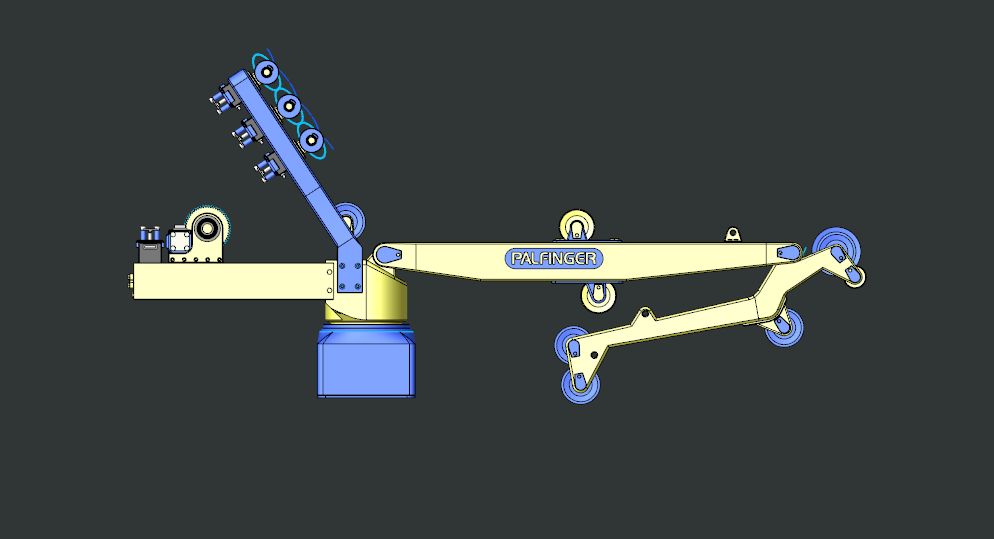
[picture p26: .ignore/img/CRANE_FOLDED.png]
Folded Position


[Back](../README.md)

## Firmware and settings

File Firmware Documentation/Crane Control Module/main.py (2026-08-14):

#MOTOR RC DECODING AND MOTOR COMMANDS
from velo import stacy, encoder, link
from machine import UART, Pin, SPI, WDT
import struct, time, gc, bisect, umatrix, math




'''===========================================================================================================
DECLARE ALL INPUTS AND OUTPUTS
RELATED TO MOTOR FUNCTION

FOR MOTOR:
OBJECTNAME = stacy(PUL,DIR)

FOR ENCODER:
OBJECTNAME = encoder(SDA,SCL,CHANNEL,SAVE ID, FREQUENCY[Hz], AVERAGE OVER X READS)

FOR LINK:
OBJECTNAME = link(MOTOR,ENCODER)
'''

#DECLARE MOTOR WIRING
jib2 = stacy(0,1)
jib1 = stacy(3,2)
comp1 = stacy(8,20)
comp2 = stacy(11,10)
winch = stacy(13,12)
boom = stacy(15,14)
slew1 = stacy(6,7,rid=1) #rid = 1 
slew2 = stacy(22,21)

#DECLARE ENCODERS
time.sleep(0.5)
Ejib2 = encoder(26,27,ch=5,sid=1,freq=60,mva=1)
Eboom = encoder(26,27,ch=6,sid=2,freq=60,mva=1)
Ejib1 = encoder(26,27,ch=7,sid=3,freq=60,mva=1)
Ecomp = encoder(26,27,ch=3,sid=5,freq=60,mva=1)
Ewinch = encoder(26,27,ch=4,sid=4,freq=60,mva=1)

#DECLARE MOTOR LINK
Ljib2 = link(jib2,Ejib2)

'''===========================================================================================================
LOAD ALL LOOKUP TABLES INTO MEMORY
 - BOOM ANGLE LOOKUP
 - RELATIVE BOOM SPEED LOOKUP
 - JIB ANGLE LOOKUP

'''

#LOAD BOOM LOOKUP TABLE
boom_pos : list = []
ang_deg  : list = []
with open('boom_angle.csv','r') as file:
    for line in file:
            row = line.rstrip('\n').rstrip('\r').split(',')
            boom_pos.append(int(row[0]))
            ang_deg.append(int(row[1]))
del file; del line; del row;
gc.collect()

#LOAD RELATIVE BOOM SPEED
jib1_speeds : list = []
jib2_speeds : list = []
ang_deg_boom : list = []
with open('boom_speed.csv','r') as file:
    for line in file:
        row = line.rstrip('\n').rstrip('\r').split(',')
        ang_deg_boom.append(int(row[0]))
        jib1_speeds.append(float(row[1]))
        jib2_speeds.append(float(row[2]))
del file; del line; del row;
gc.collect()

#JIB ANGLE LOOKUP TABLE
row = []
jib_set = []
with open('jib_angle.csv','r') as f:
    data = f.read()
for line in data.split('\r'):
    line = line.strip().strip('[]')
    if not line:
        continue
    row = [int(x) for x in line.split(',')]
    jib_set.append(row)
del f; del row; del line; del data;
#print(jib_set)

'''===========================================================================================================
USE LOOKUP TABLES TO CALCULATE
-BOOM ANGLE
-RELATIVE BOOM SPEED
-JIB ANGLE
'''

#BOOM ANGLE CALCULATION
def boom_angle(l,bp,ad):
    if bp == None:
        return 0
    if l >= 4875:
        return 70
    idex = bisect.bisect(bp,l)
    return ad[idex]

#BOOM SPEED CALCULATION
def boom_speed(act_angle,ang_deg_boom,jib1,jib2):
    if act_angle >= 70:
        return 0.97,0.79
    else:
        idex = bisect.bisect(ang_deg_boom,act_angle)
        return jib1[idex],jib2[idex]

#JIB ANGLE CALCULATION
def jib_angle(boom_angle,jib1e,file):
    jib1pos = []
    jib2pos = []
    offset = 2859
    if jib1e is None:
        return 0
    jibcheck = -jib1e #+ offset
    #print(file)
    for i in range(len(file)):
        #print(boom_angle,i)
        if i == boom_angle:
            sline = file[i]
    del i;
    try:
        l = enumerate(sline)
        for j, info in l:
            if j % 2 == 1:
                jib1pos.append(int(sline[j]))
            #elif j % 2 == 0:
            #    jib2pos.append(int(sline[j]))
        
        del l; del j; del info;
        idex = bisect.bisect(jib1pos,jibcheck)
        #print(idex)
        del jib1pos; del jib2pos;
    except Exception as e:
        print(f"{e}")
        idex = 0
    return 132 - idex*2

'''===========================================================================================================
CALCULATE
-WIRE POSITION
-COMPENSATOR POSITION
-SLEWING DEAD RECKONING
'''

#WIRE POSITION CALCULATION
def wlcalc(read):
    if read <= 0:
        read = -read
    read += 24840
    #print(read)
    i = 0
    length = 0
    gear_ratio = 2.7
    resolution = 400 * gear_ratio
    partial_spool = read % resolution
    spools = read // resolution
    layers = spools // 6
    spools_remainder = spools % 6
    #print(partial_spool, spools, layers, spools_remainder)
    for i in range(int(layers)):
        length += 6*(12+2*i)*math.pi
    length += spools_remainder*(12+(2*(i+1)))*math.pi
    length += (12+2*(i+1))*math.pi*partial_spool / resolution
    
    return round(length,1)

    #Setposition is 3 layers and 5 spools
    #Wire down is encoder negative direction
    #Small gear (driving) is 20 tooth
    #Big gear (driven) is 54 tooth
    #Gear ratio is 2.7

#COMPENSATOR POSITION
def comp_pos(getpos):
    pos = round((getpos) * 110/1160,1)
    if pos >= 110:
        Ecomp.setpos(1160)
        pos = 110.0
    elif pos <= 0:
        Ecomp.setpos(0)
        pos = 0.0
    return pos

    #front to back
    #0mm == fully forward
    #110mm == fully back

#SLEWING DEAD RECKONING
def slew_reck():
    steppos = slew1.getreck()
    angpos =steppos*360 / (38500)  % 360  //1
    return round(angpos,1)

'''===========================================================================================================
HEAVE COMPENSATION INITIALIZATION AND
HEAVE COMPENSATION CALCULATION
'''

#HEAVE COMPENSATION INITIALIZATION
sequence = [0,0,0]
count_over = 0
count_under = 0
def compensate(heave_save, hsave, sequence):
    global count_over, count_under
    #time.ticks_ms()
    hspeed  = -(heave_save+hsave) * 1160/110 *1
    limit = 5
    if abs(hspeed) <= limit:
        #count_under += 1
        hsave += heave_save
        hspeed = 0
        if abs(heave_save) <= 0.2:
            sequence = [sequence[1], sequence[2], None]
        else:
            sequence = [sequence[1], sequence[2], 'On']
        if sequence == [None, None, None]:
            COMP_OFF()
        #print(sequence)
        return hspeed, heave_save, hsave, sequence
    #count_over += 1
    if save_comp < 108 and hspeed >= limit:
        COMP_ON(1)
        COMP_SPD(hspeed,1)
        pass
    elif save_comp > 2 and hspeed <= -limit:
        COMP_ON(0)
        COMP_SPD(-hspeed,0)
        pass
    hsave = 0
    return hspeed, heave_save, hsave, sequence

#===== HEAVE CALCULATION ======
def heave_calc(POS, th1,th2,th3,th4,rolld,hd):
    th4 = -th4
    degrad = math.pi / 180
    
    #POS      TUPLE POSITION VECTORS
    #TH1            ROLL ANGLE (RAD)
    #TH2            SLEW ANGLE (RAD)
    #TH3            BOOM ANGLE (RAD)
    #TH4            JIB  ANGLE (RAD)
    #ROLLD    ANGULAR VELOCITY (RAD/S)
    #HD       LINEAR  VELOCITY (mm/S)
    
    #OUTPUT XCDOT3  LINEAR VELOCITY 3-AXIS REP (mm/S)
    
    #Position Vectors (constant)
    P_PS, P_SB, P_BJ, P_JR = POS
    cos = math.cos
    sin = math.sin
    #Relative Rotation Matrices
    
    c1, s1 = cos(th1), sin(th1)
    c2, s2 = cos(th2*degrad), sin(th2*degrad)
    c3, s3 = cos(th3*degrad), sin(th3*degrad)
    c4, s4 = cos(th4*degrad), sin(th4*degrad)
    
    R1 = umatrix.matrix([1,0,0],[0,c1,-s1],[0,s1,c1])  #ROLL
    R21 = umatrix.matrix([c2,-s2,0],[s2,c2,0],[0,0,1]) #SLEW
    R32 = umatrix.matrix([1,0,0],[0,c3,-s3],[0,s3,c3]) #BOOM
    R43 = umatrix.matrix([1,0,0],[0,c4,-s4],[0,s4,c4]) #JIB
    #Additional Relative Rotations
    R21T = R21.transpose
    R31T = R21T * R32.transpose
    R41T = R31T * R43.transpose 
    #Absolute Rotation Matrices
    R2 = R1 * R21
    R3 = R2 * R32
    R4 = R3 * R43
    #Angluar Velocities
    W1 = umatrix.matrix([rolld],[0],[0])
    #Linear Velocity (Heave)
    #ht = umatrix.matrix([0,0,hd]).transpose
    #Lie Group
    #e3 = umatrix.matrix([0,0,1])
    #Simplify multiplication order
    R1C = P_PS*W1
    R2C_1 = R21T*W1
    R2C_2 = P_SB*R2C_1
    R3C_1 = R31T*W1
    R3C_2 = P_BJ*R3C_1
    R4C_1 = R41T*W1
    R4C_2 = P_JR*R4C_1
    
    XCDOT3 = ( R1 * R1C + R2 * R2C_2 + R3 * R3C_2 + R4 * R4C_2)
    return float(hd + XCDOT3[2][0])

'''===========================================================================================================
RADIO SETUP AND CREATE HELPER FUNCTIONS FOR SPI ANTENNA
'''

#SPI
spi = SPI(0, baudrate=2_000_000, polarity=0, phase=0,
          firstbit=SPI.MSB, sck=Pin(18), mosi=Pin(19), miso=Pin(16))
cs  = Pin(17, Pin.OUT, value=1)
#UART
uart1 = UART(1, baudrate=115200, tx=4, rx=5)

#CC1101 HELPERS
def strobe(cmd):
    cs(0); spi.write(bytes([cmd])); cs(1)

def read_status(addr):
    cs(0); spi.write(bytes([addr | 0xC0]))
    buf = bytearray(1); spi.readinto(buf); cs(1)
    return buf[0]

def write_reg(addr, val):
    cs(0); spi.write(bytes([addr, val])); cs(1)

def read_fifo(n):
    cs(0); spi.write(bytes([0xFF]))
    buf = bytearray(n); spi.readinto(buf); cs(1)
    return buf

def rssi_dbm(raw):
    return (raw - 256) / 2 - 74 if raw >= 128 else raw / 2 - 74

def flush_and_rx():
    strobe(0x36); strobe(0x3A); time.sleep_us(100); strobe(0x34)

def send_packet(data):
    strobe(0x36); strobe(0x3B); time.sleep_us(100)
    cs(0); spi.write(bytes([0x7F])); spi.write(bytes([len(data)])); spi.write(data); cs(1)
    strobe(0x35)
    deadline = time.ticks_add(time.ticks_ms(), 50)
    while read_status(0xF5) not in (0x01, 0x0D):
        if time.ticks_diff(deadline, time.ticks_ms()) <= 0:
            break
        time.sleep_us(50)

def wait_packet(timeout_ms):
    deadline = time.ticks_add(time.ticks_ms(), timeout_ms)
    prev = 0; stable = 0
    while True:
        rxb = read_status(0xFB) & 0x7F
        if rxb > 0 and rxb == prev:
            stable += 1
            if stable >= 3:
                return rxb
        else:
            stable = 0
        prev = rxb
        if time.ticks_diff(deadline, time.ticks_ms()) <= 0:
            return 0
        time.sleep_us(100)

partnum = read_status(0xF0)
version = read_status(0xF1)
print(hex(partnum))
print(hex(version))

'''===========================================================================================================
DECLARE DECODING LISTS AND
DECLARE SKEWED POSITIONAL VECTORS FOR HEAVE COMPENSATION
'''

#DECLARE PAYLOAD LISTS FOR DECODING
zero     : list = [0]
zerobool : list = [False]
DEC_AX   : list = zero*5
DEC_SPD  : list = zero*5
DEC_DIR  : list = zero*5
DEC_SW   : list = zero*7
DATA     : list = zero*6


#DECLARE POSITION VECTORS FOR HEAVE
P_PS = umatrix.matrix( [     0,	 103.6,	  0.0],
                           [-103.6,	     0,	   0.0],
                           [   0.0,	  0.0,	     0] )
#(0,0,103.6)
    
P_SB = umatrix.matrix( [     0,	 -76.67,	22.58],
                           [76.67,	     0,	   0.0],
                           [-22.58,	  0.0,	     0] )
#(0,22.6,76.7)
P_BJ = umatrix.matrix( [     0,	   0.0,	500.0],
                           [  0.0,	     0,	   0.0],
                           [ -500.0,	  0.0,	     0] )
#(0,500,0)    
P_JR = umatrix.matrix( [      0,	110.2,	286.4],
                        [ -110.2,	      0,	    0.0],
                        [ -286.4,	   0.0,	      0] )

#(0,286.4,-110.2)
POS = P_PS.transpose, P_SB.transpose, P_BJ.transpose, P_JR.transpose
del P_PS; del P_SB; del P_BJ; del P_JR


'''===========================================================================================================
DECLARE FUNCTION BLOCKS FOR CRANE OPERATION
'''

#FUNCTIONS ON
def SLEW_ON(dr):
    slew1.run(dr)
    slew2.run(dr)
def COMP_ON(dr):
    if dr == 0:
        dr = -1
    comp1.run(-dr)
    comp2.run(dr)
def BOOM_ON(dr):
    if dr == 0:
        dr = -1
    jib1.run(-dr)
    jib2.run(dr)
    boom.run(dr)
def JIB_ON(dr):
    if dr == 0:
        dr = -1
    jib1.run(dr)
    jib2.run(dr)
def WINCH_ON(dr):
    winch.run(dr)

def SINGLE_JIB_ON(dr):
    jib2.run(dr)

#FUNCTIONS OFF
def SLEW_OFF():
    slew1.stop()
    slew2.stop()
def COMP_OFF():
    comp1.stop()
    comp2.stop()
def BOOM_OFF():
    jib1.stop()
    jib2.stop()
    boom.stop()
    #DISABLE IF NOT WORKING
    #RESLACK(Ejib1.getpos(),save_boom_pos,jib_set,correction_map)
def JIB_OFF():
    jib1.stop()
    jib2.stop()
    #DISABLE IF NOT WORKING
    #RESLACK(Ejib1.getpos(),save_boom_pos,jib_set,correction_map)
def WINCH_OFF():
    winch.stop()
    
def CRANE_OFF():
    jib1.stop()
    jib2.stop()
    boom.stop()
    winch.stop()
    comp1.stop()
    comp2.stop()
    slew1.stop()
    slew2.stop()
    
#FUNCTIONS SPEED
def SLEW_SPD(spd,dr):
    slew1.speed(spd)
    slew2.speed(spd)
    
def COMP_SPD(spd,dr):
    spd = int(round(spd))
    comp1.speed(spd*2)
    comp2.speed(spd*2)
    #print(spd)
    
def BOOM_SPD(spd,dr):
    #DYNAMIC SPEED PER POSITION
    try:
        jib1s, jib2s = boom_speed(boom_angle(4675+Eboom.getavg(),boom_pos,ang_deg),ang_deg_boom,jib1_speeds,jib2_speeds)
    except Exception as e:
        print("Could not fetch Boom speed")
    finally:
        jib1s = 1.14
        jib2s = 0.8
    jib1s = int((jib1s+0.05)*spd)
    jib2s = int((jib2s+0)*spd)
    if jib1s <= 40:
        jib1s = 50
    if jib2s <= 40:
        jib2s = 50
    jib1.speed(jib1s)
    jib2.speed(jib2s)
    boom.speed(spd)
    
    del jib2s; del jib1s;
    
def JIB_SPD(spd,dr):
    jib1.speed(spd)
    #2.5 ish should theoretically be dynamic though
    jib2.speed(int(spd*2.5))
    
def WINCH_SPD(spd,dr):
    winch.speed(spd)

def SINGLE_JIB_SPD(spd,dr):
    jib2.speed(spd)

'''===========================================================================================================
CREATE RESLACKING FUNCTION
RETURNS TO LAST CORRECT LOOKUP POSITION FOR UNDERWIRE ACCORDING TO BOOM ANGLE AND JIB ANGLE

CREATE FUNCTIONALITY FOR ADDING CORRECTION MAPS TO THE RESLACKING FUNCTION
-Add correction
-Add correction range
-Create correction map
'''

def RESLACK(jib1e,bangle,jib_set,correction):
    jib1pos = []
    jib2pos = []
    jibcheck = jib1e #+ offset
    #Get jib angle list, at boom angle
    

    try:
        sline = jib_set[bangle]
        l = enumerate(sline)
        for j, info in l:
            #Odd entries in jib1
            if j % 2 == 1:
                jib1pos.append(int(sline[j]))
            #Even entries in jib2
            elif j % 2 == 0:
                jib2pos.append(int(sline[j]))
        #Intersect the list with input encoder value
        idex = bisect.bisect(jib1pos,jibcheck)
        jangle = 132 - idex*2
        #Go to jib2 of that intersection, minus offset
        if idex == 0:
            pos_goto = jib2pos[idex+1] -6771
        else:
            pos_goto = jib2pos[idex] -6771
        
        pos_nocorr = pos_goto
        val = correction.get((bangle,jangle//2),None)
        #If there is a correction entry, add it
        if val != None:
            pos_goto += int(val//1)
        
        #Ljib2.goto((-pos_goto),jib2.SPSA)
        Ljib2.goto((-pos_goto),600)
    except Exception as e:
        print(e)
    finally:
        try:
            print(pos_nocorr,'Actual target\n',pos_goto,'With correction')
        except Exception as e:
            print(e)
            
def ADD_CORRECTION(correction_map, bangle, jangle, jingle):
    correction_map[(bangle, jangle // 2)] = jingle
    return correction_map
def ADD_CORRECTION_RANGE(correction_map, bangle, jangle1, jangle2, jingle):
    diff = jangle2//2 - jangle1//2
    for i in range(diff):
        correction_map[(bangle, jangle1// 2 +i)] = jingle
def CORRECTION():
    correction_map = {}
    #ADD_CORRECTION(correction_map,bangle,jangle,jingle)
    #ADD_CORRECTION_RANGE(correction_map,bangle,jangle1,jangle2,jingle)
    
    #return list to call
    return correction_map

#Generate correction map for reslack function
correction_map = CORRECTION() 

'''===========================================================================================================
UART HELPER FUNCTION FOR MRU
'''

prev_IMU = [None,None,None,None]
prev_parts = [0,0,0,0]
def lesing():
    global prev_IMU, prev_parts
    try:
        if not uart1.any():
            return prev_parts
        
        raw = uart1.read(uart1.any())
        text = raw.decode('utf-8', 'ignore')
        
        start = text.find('<')
        end   = text.find('>')
        
        if start == -1 or end == -1 or end < start:
            return prev_parts
        
        parts = text[start+1:end].split(' ')
        if len(parts) < 4:
            return prev_parts
        
        dt    = int(parts[3]) - int(prev_IMU[3]) if prev_IMU[3] else 0
        rolld = (float(parts[0]) - float(prev_parts[0])) / (dt / 1000) if prev_IMU[0] else 0
        prev_IMU = parts[0:4]
        parts[3] = rolld
        prev_parts = parts[0:4]
        return parts[0:4]

    except Exception:
        return prev_parts

'''===========================================================================================================
DICT FOR HANDLING MOTOR COMMANDS
'''

#DICTS FOR HANDLING MOTOR COMMANDS
ACTUAL_ON    : list = zerobool*5
AXIS_MAP_ON  : dict = {     0:SLEW_ON,
                            1:BOOM_ON,
                            2:JIB_ON,
                            4:COMP_ON,
                            3:WINCH_ON,
                            9:SINGLE_JIB_ON
                                        }
AXIS_MAP_OFF : dict = {     0:SLEW_OFF,
                            1:BOOM_OFF,
                            2:JIB_OFF,
                            4:COMP_OFF,
                            3:WINCH_OFF,
                                       }
AXIS_MAP_SPD : dict = {     0:SLEW_SPD,
                            1:BOOM_SPD,
                            2:JIB_SPD,
                            4:COMP_SPD,
                            3:WINCH_SPD,
                            9:SINGLE_JIB_SPD,
                                        }

'''===========================================================================================================
INITIALIZE RADIO TRANSCIEVER
CONFIGURE TRANSCIEVER FUNCTION
'''


# CC1101 INITIALIZE
cs(0); time.sleep_us(5); cs(1); time.sleep_us(40)
cs(0); time.sleep_us(5); cs(1); time.sleep_ms(100)
strobe(0x30); time.sleep_ms(100)

config = [
    #(0x00,0x01),
    (0x02,0x06),(0x03,0x47),(0x04,0xD3),(0x05,0x91),
    (0x06,0x3D),(0x07,0x04),(0x08,0x45),(0x0A,0x00),
    (0x0B,0x06),(0x0C,0x00),(0x0D,0x10),(0x0E,0xA7),
    (0x0F,0x62),(0x10,0xCA),(0x11,0x83),(0x12,0x93),
    (0x13,0x22),(0x14,0xF8),(0x15,0x34),(0x17,0x3F),
    (0x18,0x18),(0x19,0x16),(0x1A,0x6C),(0x1B,0x43),
    (0x1C,0x40),(0x1D,0x91),(0x21,0x56),(0x22,0x10),
    (0x23,0xE9),(0x24,0x2A),(0x25,0x00),(0x26,0x1F),
    (0x2C,0x81),(0x2D,0x35),(0x2E,0x09),
]
for addr, val in config:
    write_reg(addr, val)
cs(0); spi.write(bytes([0x3E | 0x40, 0xC0])); cs(1)



'''===========================================================================================================
FINAL INITALIZATION BEFORE COMPUTING LOOP
'''

#INITIALIZE POSITIONS FOR BROADCAST
save_boom_pos = boom_angle(-Eboom.getavg(),boom_pos,ang_deg) if Eboom.getavg() is not None else 0
save_jib_pos  = jib_angle(save_boom_pos,-Ejib1.getavg(),jib_set) if Ejib1.getavg() is not None else 0
save_slew= slew_reck()
save_comp=comp_pos(Ecomp.getavg()) if Ecomp.getavg() is not None else 0
save_wire=wlcalc(Ewinch.getavg()) if Ewinch.getavg() is not None else 0

#DECLARE REFRESH SPEEDS FOR REPEATING FUNCTIONS
ENCODER_RECENT         : int = 0
ENCODER_REFRESH        : int = 1800 #ms between refreshes on encoder active code
PAYLOAD_PACKET_RECENT  : int = 0
PAYLOAD_PACKET_REFRESH : int = 100 #ms between refreshes on decoded data and motor signals
POS_RECENT             : int = 0
POS_REFRESH            : int = 100 #ms
HEAVE_RECENT           : int = 0
HEAVE_REFRESH          : int = 80 #ms
hsave = 0
heave_on = 0
del zero; del zerobool;

print("System Initialized")
flush_and_rx()

#CLEAR UART BUFFER
def clear_rx_buffer(uart):
    uart.read(uart.any())
clear_rx_buffer(uart1)
timing = 0

#Watchdog timer for automatic restart after error code
#wdt = WDT(timeout=7000)

'''===========================================================================================================
COMPUTING LOOP
'''
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

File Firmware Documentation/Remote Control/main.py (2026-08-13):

#RF TEST
import struct, time
from machine import Pin, I2C, SPI, ADC
from pcf8574 import PCF8574
from hd44780 import HD44780
from lcd import LCD
import _thread

i2c = I2C(0, sda=Pin(0), scl=Pin(1), freq=400000)
pcf = PCF8574(i2c)
hd44780 = HD44780(pcf, num_lines=2, num_columns=16)
lcd = LCD(hd44780, pcf)
lcd.backlight_on()
# -- ENCODER, ANALOG STICKS, SWITCH MULTIPLEX SETUP -----
b_pin = Pin(15, Pin.IN, Pin.PULL_UP)   #EC11
s_pin = Pin(2, Pin.IN, Pin.PULL_UP)   #EC11
d_pin = Pin(12, Pin.IN, Pin.PULL_UP)    #EC11

MPS00 = Pin(9, Pin.OUT, value = 0)    #AMALOG
MPS01 = Pin(20, Pin.OUT, value = 0)    #ANALOG
MPS02 = Pin(3, Pin.OUT, value = 0)    #ANALOG
MPS10 = Pin(6, Pin.OUT, value = 0)    #SWITCH
MPS11 = Pin(7, Pin.OUT, value = 0)    #SWITCH
MPS12 = Pin(28, Pin.OUT, value = 0)    #SWITCH

API = ADC(Pin(26))                    #ANALOG SIGNAL
SWI = Pin(10, Pin.IN, Pin.PULL_UP)    #SWITCH SIGNAL

RF = Pin(4, Pin.OUT, value=0)         #LED
MODE = Pin(11, Pin.OUT, value=0)      #LED
WNCH = Pin(13, Pin.OUT, value=0)      #LED
JIB = Pin(22, Pin.OUT, value=0)       #LED
LQIH = Pin(21, Pin.OUT, value=0)      #LED
LQIL = Pin(27, Pin.OUT, value=0)      #LED
DUMMY = Pin(8, Pin.OUT, value=0)     #DUMMY




#BOOLS AND INDEXES FOR ENCODER
MENU_ACTIVE = False
RECENT_INPUT = False
TIME_RECENT = 0
MENU_TIMEOUT = 5000
SPEED_INDEX = 10+1
CURRENT_INDEX = 0
zero = [0]
SPD_S = zero*SPEED_INDEX
SCREEN_REFRESH = 350
SCREEN_RECENT = 0
LED_RECENT = 0
LED_REFRESH = 500
INDEX_TEXT = {
                 0:"COMP MAX",
                 1:"SLEW MIN",
                 2:"SLEW MAX",
                 3:"BOOM MIN",
                 4:"BOOM MAX",
                 5:"JIB  MIN",
                 6:"JIB  MAX",
                 7:"WNCH MIN",
                 8:"WNCH MAX",
                 9:"COMP MIN",
                10:"COMP MAX",
                }

previous_value = True  #EC11
button_down = False    #EC11
LEFT = False           #EC11
RIGHT = False          #EC11

#ARGS FOR ANALOG MULTIPLEXER
JOY = zero*8 #CHANNEL VALUES
AX  = zero*6 #AXIS ON, OFF
DRM = zero*6 #AXIS DIRECTION
DZ  = zero*6 #Deadzone
MID = zero*6 #Joystick calibration
MIS = zero*6 #Min speed
MAS = zero*6 #Max speed
STR = zero*6 #Stroke
SPD = zero*6 #SPEED OUTPUT
channels = 8 #CHANNEL NUMBER AMOUNT
SW_LIST = zero*8  # LIST FOR STORING BUTTON AND SWITCH INFO
MAP_AXIS = {
#     0:0,1:1,2:2,3:3,4:4,5:5,6:6,7:7
        0:0, #SLEW
        1:1, #BOOM
        2:3, #WNCH
        3:2, #JIB
        5:4, #COMP
        4:6,
        6:6,
        7:6,
                }
LED_ADDRESS = {
                0:DUMMY.value, #DUMMY.value
                1:DUMMY.value,   #JIB.value
                2:WNCH.value, #DUMMY.value
                3:MODE.value, #DUMMY.value
                4:JIB.value,    #RF.value
                5:DUMMY.value,  #MODE.value
                6:RF.value,  #WNCH.value
                7:DUMMY.value, #DUMMY.value
                    }

#------------------------------------------
#                  RC OUTPUT BYTES
M0 : int = 0          #AXIS 0 Byte
M1 : int = 0          #AXIS 1 Byte
M2 : int = 0          #AXIS 2 Byte
M3 : int = 0          #AXIS 3 Byte
M4 : int = 0          #AXIS 4 Byte
M : list = zero*5    #LIST MOTOR BYTES
SW_BYTE : int  = 0    #SWITCH BYTE


#define functions for sweeping analog multiplexer

def chcheck(f,JOY,MAP_AXIS):
    n = bin(f)
    n = n.replace('0b','')
    while len(n) < 3:
        n = '0' + n
    time.sleep_us(50)
    MPS00.value(int(n[0]))
    time.sleep_us(50)
    MPS01.value(int(n[1]))
    time.sleep_us(50)
    MPS02.value(int(n[2]))
    
    #Debug BINARY SELECTOR
    #print(MPS00.value(),MPS01.value(),MPS02.value())
    time.sleep_us(100)
    JOY[MAP_AXIS.get(f)] = round(API.read_u16()*100 / 65535)
    
    return JOY

def chsweep(n,JOY,MAP_AXIS):
    for i in range(n):
            chcheck(i,JOY,MAP_AXIS)
            time.sleep_us(100)
    return JOY

def chchecks(f):
    n = bin(f)
    n = n.replace('0b','')
    while len(n) < 3:
        n = '0' + n
    MPS10.value(int(n[0]))
    MPS11.value(int(n[1]))
    MPS12.value(int(n[2]))
    return SWI.value()
def chsweeps(n,SW_BYTE):
    for i in range(n):
        SW_LIST[i] = chchecks(i)
        time.sleep_us(10)
    return SW_LIST
    
#SET DEFAULTS FOR ANALOG MULTIPLEXER LISTS
for i in range(len(DZ)):
    DZ[i] = 20
    MID[i] = 50
    MIS[i] = 200
    MAS[i] = 1200
    STR[i] = STR[i] = 100 - MID[i] - DZ[i]

#ASSIGN MIS MAS TO SPD_S
for i in range(len(SPD_S)):
    if i == 0:
        pass
    elif i%2 == 1:
        SPD_S[i] = int(MIS[(i//2)+1]/100)
    elif i%2 == 0:
        SPD_S[i] = int(MAS[(i//2)]/100)
    
# ── SPI setup ────────────────────────────────────────────────────────────────
spi  = SPI(0, baudrate=2_000_000, polarity=0, phase=0,
           firstbit=SPI.MSB, sck=Pin(18), mosi=Pin(19), miso=Pin(16))
cs   = Pin(17, Pin.OUT, value=1)
#gdo0 = Pin(14, Pin.IN)

# ── Radio helpers ─────────────────────────────────────────────────────────────
def strobe(cmd):
    cs(0); spi.write(bytes([cmd])); cs(1)

def read_status(addr):
    cs(0); spi.write(bytes([addr | 0xC0]))
    buf = bytearray(1); spi.readinto(buf); cs(1)
    return buf[0]

def write_reg(addr, val):
    cs(0); spi.write(bytes([addr, val])); cs(1)

def read_fifo(n):
    cs(0); spi.write(bytes([0xFF]))
    buf = bytearray(n); spi.readinto(buf); cs(1)
    return buf

def rssi_dbm(raw):
    return (raw - 256) / 2 - 74 if raw >= 128 else raw / 2 - 74

def flush_and_rx():
    strobe(0x36); strobe(0x3A); time.sleep_us(100); strobe(0x34)

def send_packet(data):
    strobe(0x36); strobe(0x3B); time.sleep_us(100)
    cs(0); spi.write(bytes([0x7F])); spi.write(bytes([len(data)])); spi.write(data); cs(1)
    strobe(0x35)
    deadline = time.ticks_add(time.ticks_ms(), 100)
    while read_status(0xF5) not in (0x01, 0x0D):
        if time.ticks_diff(deadline, time.ticks_ms()) <= 0:
            break
        time.sleep_us(50)

def wait_packet(timeout_ms):
    deadline = time.ticks_add(time.ticks_ms(), timeout_ms)
    prev = 0; stable = 0
    while True:
        rxb = read_status(0xFB) & 0x7F
        if rxb > 0 and rxb == prev:
            stable += 1
            if stable >= 3:
                return rxb
        else:
            stable = 0
        prev = rxb
        if time.ticks_diff(deadline, time.ticks_ms()) <= 0:
            return 0
        time.sleep_us(100)

# ── CC1101 init ───────────────────────────────────────────────────────────────
cs(0); time.sleep_us(5); cs(1); time.sleep_us(40)
cs(0); time.sleep_us(5); cs(1); time.sleep_ms(100)
strobe(0x30); time.sleep_ms(100)
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

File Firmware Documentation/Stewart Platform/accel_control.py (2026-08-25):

from accel import stacy
from machine import Pin
import gc
import time

#Create Objects and Dict
enab_p = Pin(20,Pin.OUT)
s1 = stacy(0,1)
s2 = stacy(8,9)
s3 = stacy(6,5)

s4 = stacy(28,18)
s5 = stacy(26,22)
s6 = stacy(21,19)

dm = {1:s1,2:s2,3:s3,4:s4,5:s5,6:s6}
#Disable motors
enab_p.value(0)  
    
#==================-----------============ LOOP ==========-----------==============
def loop(en,sps,asp):
    enab_p.value(0)
    #start time
    st_time = time.ticks_ms()
    #static values
    csp = [0,0,0,0,0,0]
    end_time = [0,0,0,0,0,0]
    en_ref = []
    for i in range(len(en)):
       en_ref.append(en[i])
       if sps[i] <= 40 and en[i] != 0:
           sps[i] = 45
    ivl = []
    for i in range(6):
        ivl.append((1000000*asp[i]/sps[i])+time.ticks_us()) 
    while True:
        #-----------------------#
        #		Clock			#
        c_time = time.ticks_us()#
        us_cspeed = 1000
        #-----------------------#
        for i in range(6):
            if en[i] != 0 and ivl[i] >= c_time:
                if csp[i] == 0:
                    csp[i] = csp[i]+1
                    dm.get(i+1).speed(sps[i])
                    dm.get(i+1).run(en[i])
            elif ivl[i] < c_time:
                dm.get(i+1).stop()
                en[i] = 0
                if end_time[i] == 0:
                    end_time[i] = time.ticks_ms()
        if en == [0,0,0,0,0,0]:
            enab_p.value(1)
            print('Total time',(max(end_time)-st_time)/1000,'seconds')
            times = [((a-st_time)/1000)*b for a,b in zip(end_time,sps)]
            times_ac = [(a*b/4)//1 for a,b in zip(en_ref,times)]
            print(times_ac,'\n')
            del ivl
            del asp
            del en
            del sps
            del times
            del times_ac
            #print('after loop:',gc.mem_free()//1024)

            
            
            break
        l_time = time.ticks_us()
        if l_time - c_time <= us_cspeed:
            time.sleep_us(l_time-c_time)
    return

#CSV
def csv_readfile(filename):
    max_index = 0
    with open(filename,'r') as file:
        for line in file:
            max_index += 1
    for i in range(max_index//3):
        csv_data = []
        en_ = []
        sps_ = []
        asp_ = []
        read_index = 0
        with open(filename,'r') as file:
            for line in file:
                if i*3 == read_index or i*3+1 == read_index or i*3+2 == read_index:
                    row = line.strip().split(',')
                    csv_data.append(row)
                read_index += 1
        en_ = csv_data[0]
        sps_ = csv_data[1]
        asp_ = csv_data[2]
        for i in range(len(en_)):
            en_[i] = int(en_[i])
            sps_[i] = int(sps_[i])
            asp_[i] = int(asp_[i])
        del csv_data
        loop(en_,sps_,asp_)
        gc.collect()
    enab_p.value(1)

#def csv_readfile_old(filename): #### old version
#    csv_data = []
#    en_ = []
#    sps_ = []
#    asp_ = []
#    en_master = []
#    sps_master = []
#    asp_master = []
    #max_index = 0
    #with open(filename,'r') as file:
    #    for line in file:
    #        max_index += 1
#    with open(filename,'r') as file:
#        for line in file:
#            row = line.strip().split(',')
#            csv_data.append(row)
#    for i in range(len(csv_data)/3):
#        if not csv_data[i*3][0] == 'W':
#            en_ = csv_data[i*3]
#            sps_ = csv_data[(i*3)+1]
#            asp_ = csv_data[(i*3)+2]
#            for i in range(len(en_)):
#                en_[i] = int(en_[i])
#                sps_[i] = int(sps_[i])
#                asp_[i] = int(asp_[i])
#                if sps_[i] == 0:
#                    sps_[i] = 1
#            en_master.append(en_)
#            sps_master.append(sps_)
#            asp_master.append(asp_)
#    #Garbage collection
#    en_ = None
#    sps_ = None
#    asp_ = None
#    csv_data = None
#    #Run
#    for i in range(len(en_master)):
#        loop(en_master[i],sps_master[i],asp_master[i])
#        print('in csv writer: ',gc.mem_free()//1024)
#    enab_p.value(1)
csv_readfile('step_stew.csv')

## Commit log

2026-08-06 Started writing documentation for CCM wiring
2026-08-06 Fixed broken hexes, and invalid syntax in power wiring schematic
2026-08-06 You know the drill by now
2026-08-06 Added more folders, moved wiring schematic into correct file, and wrote a bare bones README.md
2026-08-06 Updated content of CMM Wiring.md
2026-08-09 Added STL files for stewart platform
    [SP-AC-01.stl, SP-AC-02.stl, SP-AC-04.stl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]
2026-08-09 Added nearly all crane files, and remote files. Added CAD catalogue file explorer
    [KBW-AF-01.stl, KBW-AF-02.stl, KBW-AF-03.stl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]
2026-08-09 Replaced some STL files with corrected ones, updated main README.md and CAD_catalogue.md
    [KBW-BM-04.stl, KBW-BM-05.stl, KBW-BM-06.stl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]
2026-08-09 Updated Stewart Platform wiring, created new .mmd files for said graphs
2026-08-13 Added firmware from microcontrollers
    [boom_angle.csv, boom_speed.csv, jib_angle.csv]
2026-08-14 Added GPIO numbering to CCM wiring diagram & Started documenting CCM main.py
2026-08-25 Added all scripts for Platform, Started writing Rigging Guide.md, corrected some wiring diagrams and associated mmd files.
    [current_position.csv, qtest.csv, scode.csv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]
